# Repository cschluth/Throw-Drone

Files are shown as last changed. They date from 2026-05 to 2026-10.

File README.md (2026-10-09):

# Throw-Drone

A small, hand-throwable 65 mm quadcopter that will detect a throw, stabilize itself mid-air, and hover.

https://github.com/user-attachments/assets/fbd82480-2b36-4a60-ba84-f2fc82b2668f

*First flight on the PLA prototype frame.*

The assembled drone

*Phase 1 build: the assembled quadcopter on the PLA prototype frame.*

## Status

**Phase 1: Base quadcopter (almost complete)**
- All four motors soldered to the ESC and configured in Betaflight
- Receiver wired to the flight controller (RX and TX)
- Successful first flight on a PLA prototype frame
- Tuning PIDs in Betaflight to make the flight more controllable (in progress)

**Phase 2: Throw detection (planned)**
- Finalize and reprint the frame in PETG-CF
- Wire the ESP32-S3 to the flight controller
- Test and tune the throw-detection logic on real hardware

Started June 2026. This is a work in progress, and I update this page as I go.

## Why I'm building it

I'm a mechanical engineering student, and I wanted a project of my own outside of class. I'm interested in electronics, and I wanted something that combined that with the more traditional mechanical side, like CAD, 3D printing, and building prototypes. A drone was a good fit because it needs both: a frame that has to be designed and printed, and electronics that have to be wired, configured, and programmed to work with it. I added the throw-and-hover idea because I thought it would be cool, and it gives the drone a trick of its own instead of just flying around. I'm learning most of this as I go, so I'm building it in stages, starting with a simple version that flies and adding the harder parts after.

## How it will work

1. An IMU detects that the drone has been thrown.
2. The motors spool up.
3. The flight controller recovers the drone's attitude.
4. The drone stabilizes and hovers.

The logic is a five-state machine: `IDLE`, `HELD`, `RELEASED`, `FREEFALL`, `STABILIZING`.

## Hardware

| Part | Model |
|---|---|
| Flight controller / ESC | SpeedyBee F405 Mini BLS 35A stack |
| Motors | Happymodel RS1102 10000KV (2S) |
| Battery | OVONIC 2S 450 mAh LiPo (XT30) |
| Props | HQProp 65 mm |
| Receiver | ELRS C8 nano |
| Microcontroller | Seeed XIAO ESP32-S3 |
| 3D printer | Elegoo Centauri Carbon |

Weight: ~80 g (estimated)

## Design

- Designed in Fusion 360
- Layered frame: top plate, a structural middle plate with tapered arms, and a battery bay below
- Through-bolts with captured hex nut pockets, since snap fits were impractical at this scale
- PLA prototypes for fit and flight checks, then PETG-CF for the final frame

### CAD: mid plate

<table>
  <tr>
    <td align="center">
      Mid plate with visible edges<br>
      <sub>Mid plate: visible edges</sub>
    </td>
    <td align="center">
      Mid plate with hidden edges<br>
      <sub>Mid plate: hidden edges</sub>
    </td>
  </tr>
</table>

### Prototype frames

<table>
  <tr>
    <td align="center">
      Prototype frame 1<br>
      <sub>Frame prototype 1</sub>
    </td>
    <td align="center">
      Prototype frame 2<br>
      <sub>Frame prototype 2</sub>
    </td>
  </tr>
  <tr>
    <td align="center">
      Prototype frame 3<br>
      <sub>Frame prototype 3</sub>
    </td>
    <td align="center">
      Prototype frame 4<br>
      <sub>Frame prototype 4</sub>
    </td>
  </tr>
</table>

## Software

The ESP32-S3 firmware is in the [`code`](code) folder, written in Arduino C++.

**Note:** The initial version of this code was written with Claude AI assistance. I designed the state machine and am working through the code to understand how it works. The IMU input is currently simulated for bench testing, and nothing has been tested on the drone yet.

## What I've learned so far

- **Betaflight settings can silently fail to save in the GUI.** The CLI is more reliable for critical config like serial ports.
- **The FC's 5V pad is battery-powered, not USB-powered.** Only 3.3V is live over USB, which is why my receiver showed no activity during USB-only testing.
- **UART wiring is always crossed.** Receiver TX goes to FC RX, and receiver RX goes to FC TX.
- **PLA is fine for setup and low-throttle checks, but not for throw tests.** It's brittle and weak near the motors, so the final frame will be PETG-CF.

## Roadmap

- [x] Select parts and design the frame
- [x] Print PLA prototype and test-fit electronics
- [x] Solder and configure all four motors
- [x] First flight
- [ ] Tune PIDs in Betaflight (in progress)
- [ ] Finish frame design
- [ ] Reprint in PETG-CF
- [ ] Add prop guards before throw tests
- [ ] Wire ESP32-S3 to the flight controller
- [ ] Test throw detection on hardware
- [ ] Document the minimum safe throw height

## Contact

Charlie Schluth, Mechanical Engineering, Penn State

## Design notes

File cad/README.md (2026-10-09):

STL files for the drone frame, exported for printing.

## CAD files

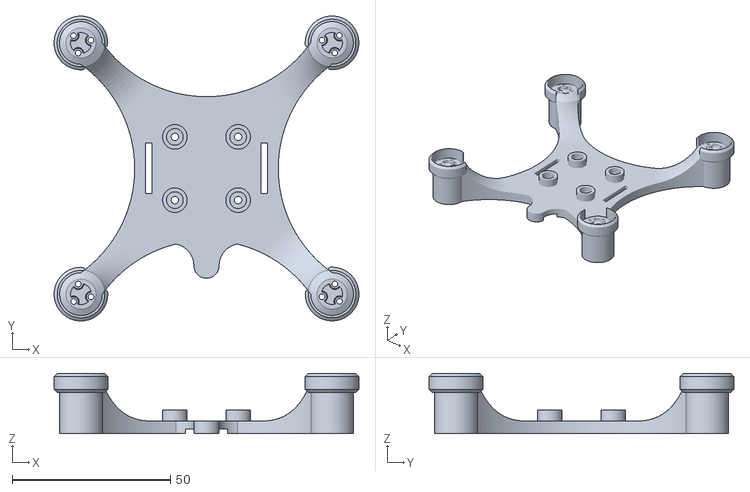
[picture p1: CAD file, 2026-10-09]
cad/midplateP1.stl
96.4 x 96.4 x 19.0

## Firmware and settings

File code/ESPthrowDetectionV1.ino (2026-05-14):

// ============================================
// THROW DETECTION SYSTEM
// XIAO ESP32-S3
// Drone catch-itself project
// ============================================

// --- PIN DEFINITIONS ---
// NEW - correct for XIAO ESP32-S3
#define BUTTON_PIN    D1    // button on drone body
#define LED_PIN       LED_BUILTIN  // onboard LED
#define FC_TX_PIN     D6    // UART TX to flight controller
#define FC_RX_PIN     D7    // UART RX from flight controller

// --- TUNING CONSTANTS ---
// These values will need adjustment during real world testing
// Start with these defaults and tune from there

#define FREEFALL_THRESHOLD    0.3   // g-force below this = freefall
                                    // 1.0 = normal gravity
                                    // 0.3 = significant freefall detected

#define THROW_ACCEL_THRESHOLD 1.8   // g-force above this = throw motion
                                    // detects the acceleration spike of a throw

#define STABILIZE_TIMEOUT     2000  // milliseconds to attempt stabilization
                                    // before giving up and returning to idle

#define DEBOUNCE_DELAY        50    // milliseconds for button debounce
                                    // prevents false triggers from button noise

// --- STATE MACHINE DEFINITIONS ---
// Drone can only be in one state at a time
// States progress in order during a throw sequence

#define STATE_IDLE          0  // sitting still, waiting for button press
#define STATE_HELD          1  // button held, motors at idle, ready to throw
#define STATE_RELEASED      2  // button just released, checking for throw
#define STATE_FREEFALL      3  // throw confirmed, waiting for tumble detection
#define STATE_STABILIZING   4  // sending stabilize command to flight controller

// --- GLOBAL VARIABLES ---
int currentState = STATE_IDLE;
unsigned long stateEntryTime = 0;    // tracks when we entered current state
unsigned long lastDebounceTime = 0;  // tracks last button state change
bool lastButtonState = HIGH;         // previous button reading
bool buttonState = HIGH;             // current confirmed button state

// Simulated IMU values for bench testing
// Replace with real IMU reads when FC telemetry is connected
float simulated_accel_x = 1.0;
float simulated_accel_y = 0.0;
float simulated_accel_z = 0.0;

// --- UART TO FLIGHT CONTROLLER ---
HardwareSerial FC_Serial(1);  // use UART1 for FC communication

// ============================================
// MSP PROTOCOL FUNCTIONS
// MSP = MultiWii Serial Protocol
// How ESP32 talks to Betaflight
// ============================================

// Calculate checksum for MSP packet
// XOR all bytes together
uint8_t calculateChecksum(uint8_t* data, int length) {
  uint8_t checksum = 0;
  for (int i = 0; i < length; i++) {
    checksum ^= data[i];
  }
  return checksum;
}

// Send MSP command to flight controller
// command = MSP command code
// data = optional payload bytes
// dataLength = number of payload bytes
void sendMSPCommand(uint8_t command, 
                    uint8_t* data = nullptr, 
                    int dataLength = 0) {
  
  // MSP packet structure:
  // $ M < dataLength command [data bytes] checksum
  
  uint8_t packet[dataLength + 6];
  packet[0] = '$';          // header byte 1
  packet[1] = 'M';          // header byte 2
  packet[2] = '<';          // direction: to FC
  packet[3] = dataLength;   // payload size
  packet[4] = command;      // command code
  
  // copy data payload if any
  for (int i = 0; i < dataLength; i++) {
    packet[5 + i] = data[i];
  }
  
  // calculate and append checksum
  packet[5 + dataLength] = calculateChecksum(
    &packet[3], dataLength + 2
  );
  
  // send over UART to flight controller
  FC_Serial.write(packet, sizeof(packet));
}

// Tell Betaflight to enter angle mode and stabilize
// This is the key command sent after throw detection
void sendStabilizeCommand() {
  // MSP_SET_RAW_RC = 200
  // Sends fake RC input to FC telling it to stabilize
  // Channel values: roll, pitch, yaw, throttle
  // 1500 = center/neutral for roll pitch yaw
  // 1100 = low throttle to start, FC manages from here
  
  uint8_t channels[16];
  
  // Roll: center (1500)
  channels[0] = 0xDC;
  channels[1] = 0x05;
  
  // Pitch: center (1500)
  channels[2] = 0xDC;
  channels[3] = 0x05;
  
  // Yaw: center (1500)
  channels[4] = 0xDC;
  channels[5] = 0x05;
  
  // Throttle: low (1100) — FC handles the rest
  channels[6] = 0x4C;
  channels[7] = 0x04;
  
  // remaining channels set to 1000 (off)
  for (int i = 8; i < 16; i++) {
    channels[i] = 0;
  }
  
  sendMSPCommand(200, channels, 16);
  
  Serial.println(">> Stabilize command sent to FC");
}

// Tell Betaflight to arm motors
void sendArmCommand() {
  // Arming is done by setting throttle low
  // and yaw full right briefly
  // then returning to center
  // Betaflight handles the actual arm sequence
  
  Serial.println(">> Arm command sent to FC");
  // Full implementation added when FC arrives
  // and we can test the exact arm sequence
}

// ============================================
// IMU FUNCTIONS
// Currently simulated for bench testing
// Replace with real MSP telemetry reads
// when flight controller is connected
// ============================================

// Read total acceleration magnitude from IMU
// Returns value in g-force units
// 1.0g = stationary on ground
// ~0.0g = freefall
// >1.5g = significant acceleration (throw)
float readAccelMagnitude() {
  
  // ---- SIMULATION MODE ----
  // Remove this block when FC is connected
  // and replace with real MSP telemetry read
  
  // Simulate different conditions for testing:
  // Comment/uncomment to test different scenarios
  
  return 1.0;   // normal gravity — stationary
  // return 0.2;   // freefall simulation
  // return 2.1;   // throw acceleration simulation
  
  // ---- END SIMULATION ----
  
  // REAL IMPLEMENTATION (uncomment when FC arrives):
  // sendMSPCommand(102);  // MSP_RAW_IMU = 102
  // wait for response
  // parse acceleration values
  // return calculated magnitude
}

// Detect if drone is in freefall
// Called immediately after button release
bool detectFreefall() {
  float accel = readAccelMagnitude();
  Serial.print("Accel magnitude: ");
  Serial.println(accel);
  return accel < FREEFALL_THRESHOLD;
}

// Detect throw acceleration spike
// Called to confirm this was a throw not just a drop
bool detectThrowAccel() {
  // In real implementation reads peak acceleration
  // from the moment of throw
  // For now simulated as always true after button release
  return true;
}

// ============================================
// LED STATUS FUNCTIONS
// Visual feedback for each drone state
// ============================================

void ledIdle() {
  // Slow single blink — waiting
  static unsigned long lastBlink = 0;
  static bool ledOn = false;
  
  if (millis() - lastBlink > 1000) {
    ledOn = !ledOn;
    digitalWrite(LED_PIN, ledOn ? HIGH : LOW);
    lastBlink = millis();
  }
}

void ledHeld() {
  // Solid on — button held, ready to throw
  digitalWrite(LED_PIN, HIGH);
}

void ledReleased() {
  // Fast blink — processing throw detection
  static unsigned long lastBlink = 0;
  static bool ledOn = false;
  
  if (millis() - lastBlink > 100) {
    ledOn = !ledOn;
    digitalWrite(LED_PIN, ledOn ? HIGH : LOW);
    lastBlink = millis();
  }
}

void ledStabilizing() {
  // Very fast blink — motors spinning up
  static unsigned long lastBlink = 0;
  static bool ledOn = false;
  
  if (millis() - lastBlink > 50) {
    ledOn = !ledOn;
    digitalWrite(LED_PIN, ledOn ? HIGH : LOW);
    lastBlink = millis();
  }
}

// ============================================
// BUTTON READING WITH DEBOUNCE
// Debounce prevents false triggers from
// electrical noise on button press/release
// ============================================

// Returns true if button is currently held
// Returns false if button is released
bool readButton() {
  bool reading = digitalRead(BUTTON_PIN);
  
  // if reading changed, reset debounce timer
  if (reading != lastButtonState) {
    lastDebounceTime = millis();
  }
  
  // only accept reading if stable for DEBOUNCE_DELAY
  if (millis() - lastDebounceTime > DEBOUNCE_DELAY) {
    buttonState = reading;
  }
  
  lastButtonState = reading;
  
  // button is active LOW (pressed = LOW)
  // because of PULL_UP resistor
  return buttonState == LOW;
}

// ============================================
// STATE MACHINE
// Core logic of the throw detection system
// Each state has entry behavior and 
// transition conditions to next state
// ============================================

void enterState(int newState) {
  currentState = newState;
  stateEntryTime = millis();
  
  // Print state transition for debugging
  switch (newState) {
    case STATE_IDLE:
      Serial.println("STATE: Idle — waiting for button");
      break;
    case STATE_HELD:
      Serial.println("STATE: Held — ready to throw");
      break;
    case STATE_RELEASED:
      Serial.println("STATE: Released — detecting throw");
      break;
    case STATE_FREEFALL:
      Serial.println("STATE: Freefall — throw confirmed");
      break;
    case STATE_STABILIZING:
      Serial.println("STATE: Stabilizing — catching drone");
      break;
  }
}

void updateStateMachine() {
  bool buttonHeld = readButton();
  
  switch (currentState) {
    
    // ---- IDLE ----
    // Waiting for button to be pressed
    case STATE_IDLE:
      ledIdle();
      if (buttonHeld) {
        enterState(STATE_HELD);
      }
      break;
    
    // ---- HELD ----
    // Button is held — drone in hand ready to throw
    // Motors at idle in Betaflight
    // Waiting for button release
    case STATE_HELD:
      ledHeld();
      if (!buttonHeld) {
        // Button released — start throw detection
        enterState(STATE_RELEASED);
      }
      break;
    
    // ---- RELEASED ----
    // Button just released
    // Check for freefall within short window
    // If no freefall detected → return to idle
    // (prevents accidental trigger from just setting drone down)
    case STATE_RELEASED:
      ledReleased();
      
      if (detectFreefall()) {
        // Freefall detected — this was a real throw
        enterState(STATE_FREEFALL);
      }
      
      // If no freefall detected within 500ms
      // assume drone was just set down, return to idle
      if (millis() - stateEntryTime > 500) {
        Serial.println("No throw detected — returning to idle");
        enterState(STATE_IDLE);
      }
      break;
    
    // ---- FREEFALL ----
    // Throw confirmed by freefall detection
    // Now waiting for tumble/orientation data
    // Then send stabilize command
    case STATE_FREEFALL:
      ledReleased();
      
      // Small delay to let drone fully clear hand
      // Then immediately command stabilization
      if (millis() - stateEntryTime > 100) {
        enterState(STATE_STABILIZING);
      }
      break;
    
    // ---- STABILIZING ----
    // Send stabilize command to flight controller
    // FC takes over and catches the drone
    case STATE_STABILIZING:
      ledStabilizing();
      sendArmCommand();
      sendStabilizeCommand();
      
      // After stabilize timeout return to idle
      // FC should have drone hovering by now
      if (millis() - stateEntryTime > STABILIZE_TIMEOUT) {
        Serial.println("Stabilization complete");
        enterState(STATE_IDLE);
      }
      break;
  }
}

// ============================================
// SETUP AND LOOP
// ============================================

void setup() {
  // Initialize serial monitor for debugging
  Serial.begin(115200);
  Serial.println("=====================================");
  Serial.println("Throw Detection System Starting...");
  Serial.println("=====================================");
  
  // Initialize pins
  pinMode(BUTTON_PIN, INPUT_PULLUP);
  pinMode(LED_PIN, OUTPUT);
  
  // Initialize UART to flight controller
  FC_Serial.begin(115200, SERIAL_8N1, 
                  FC_RX_PIN, FC_TX_PIN);
  Serial.println("FC Serial initialized");
  
  // Start in idle state
  enterState(STATE_IDLE);
  
  Serial.println("System ready");
  Serial.println("Hold button and throw to test");
}

void loop() {
  // Run state machine every loop iteration
  // This executes hundreds of times per second
  // Fast enough to catch any throw motion
  updateStateMachine();
  
  // Small delay to prevent overwhelming serial monitor
  // Remove this when timing becomes critical
  delay(10);
}

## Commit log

2026-05-14 Milestone 1 - Button detection working on breadboard
    ESP32-S3 throw detection state machine
    confirmed working with physical button.
    All five states transitioning correctly.
    False throw prevention validated.
    [ESPthrowDetectionV1.ino]
2026-10-09 Update README with Phase 1 status, CAD images, and prototype photos
    Updated project status, refined descriptions, and corrected details about the drone's development.
2026-10-09 Add README for STL files of drone frame
2026-10-09 Add mid plate STL
    [midplateP1.stl]
